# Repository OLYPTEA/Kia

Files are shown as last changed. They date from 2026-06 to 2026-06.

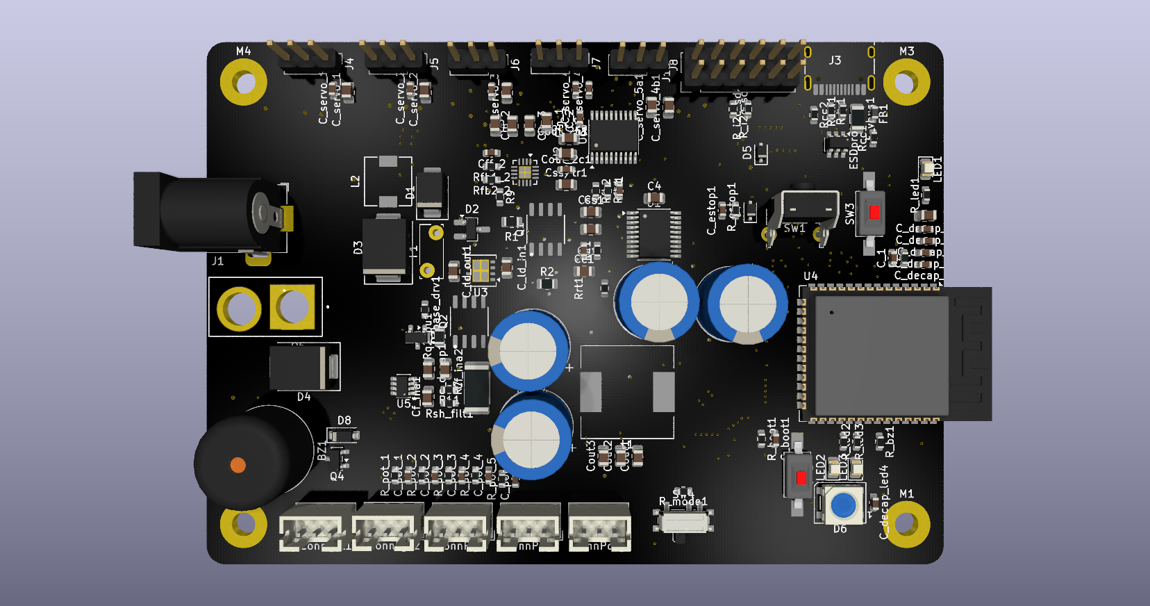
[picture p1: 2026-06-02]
1-Hardware/Kia-Arm-Ctrl.png

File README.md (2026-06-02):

#  Kia Arm Controller (ESP32-S3) By OlypTea
 (Baser sur : https://www.youtube.com/watch?v=AIsVlgopqJc )

CarteKia

Kia-Arm-Ctrl22

KiaStudio

https://github.com/user-attachments/assets/333e42ec-3789-4127-9b2e-19c26ccea488

Refonte complète (Hardware, Firmware & Software) d'un bras robotique imprimé en 3D (4 axes + pince), inspirée initialement du projet de la chaîne *Build Some Stuff*. 

Cette version abandonne le combo limité Arduino Uno + PCA9685 au profit d'une **carte sur mesure basée sur l'ESP32-S3**, capable de gérer la cinématique et l'alimentation de puissance de manière autonome.

---

##  Améliorations majeures

* **Calcul haute performance :** ESP32-S3 (Dual-core 240MHz, FPU, 16MB Flash + 8MB PSRAM Octal). Gère la cinématique directe/inverse (FK/IK) et l'interpolation par spline cubique directement en local.
* **Alimentation intégrée (6V/10A) :** Régulateur Buck synchrone TI TPS56C215 (pic à 15A) capable d'alimenter directement les servos de forte puissance (Miuzei 15 à 35kg).
* **Sécurité matérielle :** Surveillance de la puissance via INA219 et circuit d'arrêt d'urgence physique (**E-STOP** par MOSFETs) coupant la puissance sans affecter la logique du MCU.
* **Signal propre :** Abandon du PCA9685. Utilisation du périphérique natif **MCPWM** de l'ESP32-S3 avec conversion de niveau logique 3.3V vers 5V (SN74AHCT244).
* **Interface PC dédiée (Kia Studio) :** Application de contrôle et calibration 3D temps réel développée en Python (PySide6 + PyOpenGL).

---

##  Spécifications du Hardware & PCB

* **Dimensions :** 100 × 70 mm (conçu pour s'intégrer parfaitement dans l'espace de 113.5 × 80.7 mm de la base du bras / plaque MB2).
* **Stackup :** PCB 4 couches avec couches internes en cuivre épais de 2 oz (70 µm).
* **Routage :** Pistes d'alimentation VSERVO $\ge$ 3 mm et isolation stricte des masses (**Star Ground**) : connexions séparées pour le GND logique, puissance et analogique reliées en un seul point (Net tie) sous l'INA219.
* **Conception :** Réalisé sous **KiCad 10** (Schémas divisés en modules : Power, MCU, IO, Connectors).

 **Piège de routage évité :** Les GPIO 26 à 37 sont réservés à la PSRAM Octal de l'ESP32-S3 et sont strictement inutilisables.

---

##  Architecture du Firmware (Dual-Core)

Développé directement sous **ESP-IDF + FreeRTOS** pour maximiser les performances en temps réel.

* **Core 0 (PRO_CPU) : Gestion & Comms**
  * Parser USB CDC & Serveur BLE GATT (futurs services WiFi/HTTP).
  * Machine d'état principale de tout le système.
* **Core 1 (APP_CPU) : Temps Réel Strict**
  * Tâche ADC (100 Hz) : Suréchantillonnage x64, filtre EMA et hystérésis pour les 5 potentiomètres.
  * Solveur cinématique (FK/IK) et interpolation de trajectoire (Spline cubique) pour des mouvements fluides sans à-coups.
  * Driver MCPWM (50 Hz) pour le signal précis des servos (impulsions de 1 à 2 ms).
  * Supervision de sécurité (Lecture I2C en temps réel de l'INA219 & gestion de l'interruption E-STOP).

---

##  Logiciel PC : Kia Studio

Interface 3D légère basée sur une **architecture hexagonale** en Python 3.11 + PySide6 et un rendu graphique de bas niveau (pyqtgraph + PyOpenGL).

* **`proto/`** : Protocole de communication USB CDC partagé à 100 % avec le contrôleur.
* **`core/`** : Modèle cinématique pur Python et chargement des fichiers STL.
* **`ui/`** : Vue Qt, panneau de calibration 3D avec manipulation des axes XYZ (Pivot Gizmo) et sauvegarde des offsets dans un fichier de configuration JSON.

*(Note : L'application est générique. Il suffit de remplacer les modèles 3D et de rebuild l'app pour l'adapter à un autre bras possédant la même architecture).*

---

##  Modes de Fonctionnement

| Mode | Déclencheur | Logique principale | Utilisation |
| :--- | :--- | :--- | :--- |
| **Manual** | Interrupteur physique | Lecture potentiomètres $\rightarrow$ Filtre ADC $\rightarrow$ Angles $\rightarrow$ MCPWM | Test initial de chaque articulation et manipulation simple sans PC. |
| **App** | Commande PC | Cible via USB/BLE $\rightarrow$ Solveur IK $\rightarrow$ Spline cubique $\rightarrow$ MCPWM | Contrôle spatial complexe via Kia Studio, exécution de trajectoires. |
| **Calibration**| Commande / Bouton | Désactivation spline $\rightarrow$ Ajustement fin des neutres (largeur d'impulsion) $\rightarrow$ Sauvegarde NVS | Premier assemblage, remplacement de servo ou recentrage suite à un saut de dent. |
| **Fault** | E-STOP / INA219 | Coupure matérielle immédiate des servos + LED Alerte jaune & WS2812 rouge | Protection en cas de collision, blocage mécanique ou court-circuit. |

---

##  Remerciements & Références
* **Build Some Stuff** Fondateur du projet initiale
* **Espressif ESP-IDF** - Framework.
* **KiCad EDA** - Suite de conception électronique open-source.
* **PySide / Qt** - Framework UI pour Kia Studio.
* Merci aux membres de la communauté open-source pour les inspirations structurelles des bras robotiques 3D.

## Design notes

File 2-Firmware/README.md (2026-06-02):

# Kia Arm Controller — Firmware

ESP32-S3 firmware for the 4-axis + gripper robotic arm controller (PCB `Kia-Arm-Ctrl v1`).

## Stack

- **SDK**: ESP-IDF v5.3+
- **OS**: FreeRTOS (1 kHz tick, dual-core)
- **Language**: C11 + selective C++17 (no exceptions / no RTTI)
- **Build**: CMake via `idf.py`
- **Toolchain**: xtensa-esp32s3-elf-gcc 13+

## Architecture

```
app/        ModeFSM, Calibration
domain/     Kinematics (FK/IK 4DOF), JointModel
services/   Motion, Safety, CommRouter, Storage, Telemetry
hal/drv/    Servo (MCPWM), Pot (ADC continuous DMA), INA219, LED (RMT WS2812),
            Buttons (debounce), Buzzer (LEDC)
common/     err, log, ringbuf (lock-free SPSC), COBS, CRC32
```

### Real-time partitioning

| Core | Tasks |
|---|---|
| 1 (APP_CPU) | `motion` (1 kHz), `safety` (200 Hz), `pot` (ADC DMA) |
| 0 (PRO_CPU) | `usb_rx`, `mode_fsm`, `telemetry`, `btn`, `event_loop` |

Task priorities are defined in `main/app_config.h` (`KIA_PRIO_*`).
Safety has the highest priority and never blocks on I/O.

### Event bus

All cross-component coordination goes through `esp_event_loop` on `KIA_EVENT_BASE`
(see `main/app_events.h`). No globals, no implicit coupling.

## Build / Flash / Monitor

```bash
. $IDF_PATH/export.sh
idf.py set-target esp32s3
idf.py menuconfig          # adjust if needed
idf.py -p COMx flash monitor
```

To clean:
```bash
idf.py fullclean
```

## Wire protocols

### Text (debug / CLI)

Line-terminated ASCII. Commands :

```
PING                                  → PONG fw=1.0.0
STATUS                                → STATUS J=[...] XYZP=[...] I=... FAULT=... SRC=...
J <id> <deg> [duration]               → OK | ERR ...
XYZ <x> <y> <z> <pitch> [duration]    → OK | ERR ...
MODE MANUAL|APP|HOLD                  → OK
HOME                                  → OK
HOLD                                  → OK
ARM                                   → OK | ERR
CLEAR                                 → OK | ERR
SAVE                                  → OK
HELP
```

### Binary (app, COBS + CRC32)

Frames terminated by `0x00`. Body (after COBS decode):

```
struct frame {
  u8   op;
  u8   flags;
  u16  seq;
  u32  crc32;       /* CRC of op|flags|seq|payload */
  u8   payload[];
}
```

Opcodes TBD — currently the dispatcher is a stub. Extension point in
`components/svc_comm/proto_binary.c`.

## Safety model

1. **HW E-STOP** : `GPIO40` drives the P-MOSFET that gates `+VSERVO`.
   Independent of firmware liveness.
2. **HW E-STOP IRQ** : `GPIO18` falling edge → kill rail + raise `FAULT`.
3. **INA219 supervisor** : 200 Hz. Trips on instantaneous I > 8 A or
   sustained average > 5 A.
4. **Brownout detector** : hardware level 7.
5. **Task WDT** : 3 s, registered on safety task.
6. **Soft joint limits** : enforced in `dom_joint_clamp` and in motion controller.

To clear a soft fault: `CLEAR`. To clear E-STOP: release the physical button.

## Calibration

Stored in NVS namespace `kia_cal`. Per-servo: offset, pulse min/max,
inversion, angle window. Per-pot: raw min/max.

Capture from CLI :
```
J 0 0          # drive joint 0 to where you want zero
# then via dedicated calibration cmd (TODO: CAL J0 ZERO)
SAVE           # persist to NVS
```

## File layout

```
firmware/
├── CMakeLists.txt
├── sdkconfig.defaults
├── partitions.csv
├── main/
│   ├── main.c
│   ├── app_config.h         ← single source of truth for pins, limits, rates
│   └── app_events.h
├── components/
│   ├── common/              ← err, log, ringbuf, COBS, CRC32
│   ├── drv_servo/           ← MCPWM, 5 channels
│   ├── drv_pot/             ← ADC continuous + EMA + adaptive hysteresis
│   ├── drv_ina219/          ← I²C current monitor
│   ├── drv_led/             ← WS2812 (RMT) + status/fault GPIOs
│   ├── drv_buttons/         ← E-STOP + mode (ISR + debounce)
│   ├── drv_buzzer/          ← LEDC PWM tones
│   ├── dom_joint/           ← per-joint spec + state + limit clamp
│   ├── dom_kinematics/      ← FK + IK 4DOF closed-form
│   ├── svc_safety/          ← supervisor + fault FSM
│   ├── svc_motion/          ← 1 kHz controller + quintic trajectory
│   ├── svc_comm/            ← router + USB CDC + text + binary protocols
│   ├── svc_storage/         ← NVS wrappers, calibration persistence
│   ├── svc_telemetry/       ← periodic broadcast on all transports
│   ├── app_mode_fsm/        ← Boot → Idle → Manual/App/Calib/Fault/E-STOP
│   └── app_calibration/     ← capture routines
└── tests/                   ← unit tests (Unity, TODO)
```

## Coding conventions

- snake_case, header guards via `#pragma once`
- static for everything not in the public header
- no globals; module state held in a single static struct
- error type : `esp_err_t` augmented by `kia_err_t` codes
- macros : `KIA_CHK(expr)` aborts on error (init time), `KIA_RET(expr)` returns
- clang-format provided

## Status (firmware roadmap)

- [x] BLE NimBLE GATT transport (custom service, RX write + TX notify)
- [x] Binary opcode dispatch (system / motion / mode / storage / cal / OTA)
- [x] CAL CLI subcommands (`CAL J<i> ZERO|MIN|MAX`, `CAL P<i> MIN|MAX`, `CAL GEOM`)
- [x] OTA over USB CDC / BLE (`svc_ota` + opcodes 0x50–0x53)
- [x] Trajectory queue (`move_queue`, FreeRTOS-safe ring)
- [x] Jerk-limited S-curve profile (`traj_scurve_*`, switchable at runtime)
- [x] Cartesian straight-line path (`cart_path_plan_line`, subdivision + per-segment IK)
- [x] Unit tests Unity (kinematics, COBS, CRC32, ringbuf, trajectory) — `tests/`
- [x] Host CLI Python (`tools/kia_cli.py` — serial + BLE, text + binary + OTA push)
- [ ] PID closed-loop (waiting for joint encoders hardware)
- [ ] BLE pairing / bonding for production
- [ ] Web-based telemetry dashboard

## Wire protocol — binary opcodes

| Op | Direction | Body (LE) |
|---|---|---|
| 0x01 PING | req | — |
| 0x81 PONG | rsp | u8 maj, u8 min, u8 patch |
| 0x02 GET_STATUS  | req | — |
| 0x82 STATUS | rsp | 4×f32 joints, f32 grip, 3×f32 xyz, f32 pitch, u32 cur_ma, u8 fault, u8 src, u8 idle, u8 _ |
| 0x10 SET_JOINT | req | u8 idx, f32 deg, f32 dur |
| 0x11 SET_JOINTS  | req | 4×f32 joints, f32 grip, f32 dur |
| 0x12 SET_XYZ | req | 4×f32 pose, f32 dur |
| 0x13 HOME / 0x14 HOLD | req | — |
| 0x20 MODE_SET | req | u8 mode |
| 0x21 ARM / 0x22 CLEAR | req | — |
| 0x30 SAVE / 0x31 LOAD / 0x3F FACTORY | req | — |
| 0x50 OTA_BEGIN | req | u32 total, u16 chunk, u32 crc32 |
| 0x51 OTA_CHUNK | req | u32 offset, bytes data |
| 0x52 OTA_END / 0x53 OTA_ABORT | req | — |
| 0xF0 TELEMETRY | async | same payload as STATUS |
| 0xFE ACK / 0xFF NACK | rsp | (NACK) u8 reason |

NACK reasons: 1=BAD_OP 2=BAD_LEN 3=BAD_ARG 4=LIMIT 5=UNREACHABLE 6=FAULT 7=BUSY 8=NOMEM 9=BAD_STATE 0xFE=NOT_IMPL 0xFF=INTERNAL

## BLE service

| Item | Value |
|---|---|
| Service UUID  | custom 128-bit (see `transport_ble.c`) |
| RX charac | write / write-no-rsp — host → device frames |
| TX charac | notify — device → host frames |
| Device name | `KiaArm` |

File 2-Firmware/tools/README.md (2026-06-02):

# Kia Arm — Host tools

## kia_cli.py

Interactive CLI for the Kia Arm controller, supports both **USB CDC** (text + binary)
and **BLE** transports.

### Install

```bash
pip install -r requirements.txt
```

### Usage

```bash
# USB serial
python kia_cli.py serial COM5
python kia_cli.py serial /dev/ttyACM0 -b 115200

# BLE (auto-scan for "KiaArm")
python kia_cli.py ble
python kia_cli.py ble --name MyKia
```

### Commands

Text protocol (line-based, parsed by `proto_text` on device):

```
PING
STATUS
J 0 30 1.5
XYZ 150 0 120 -30 2.0
MODE MANUAL|APP|HOLD
HOME / HOLD / ARM / CLEAR / SAVE
CAL J<i> ZERO|MIN|MAX
CAL P<i> MIN|MAX
CAL GEOM <base_h> <upper> <fore> <tool>
CAL LOAD | FACTORY
HELP
```

Binary helpers (encoded COBS+CRC32 frames):

```
bping
bjoint <i> <deg>
bxyz <x y z pitch>
bhome / bsave / barm / bclear
ota <firmware.bin>          # push OTA
tlm                         # print last decoded telemetry
```

Type `q` or `exit` to quit.

### Architecture

```
KiaClient
   ├─ Transport (Serial | BLE)  — bytes in/out
   ├─ Text frames   — newline terminated
   └─ Binary frames — COBS(0x00 delim) + [op|flags|seq|crc32|body]
```

Telemetry frames (opcode 0xF0) are decoded into a `Status` dataclass and
exposed via `client.last_telemetry`.

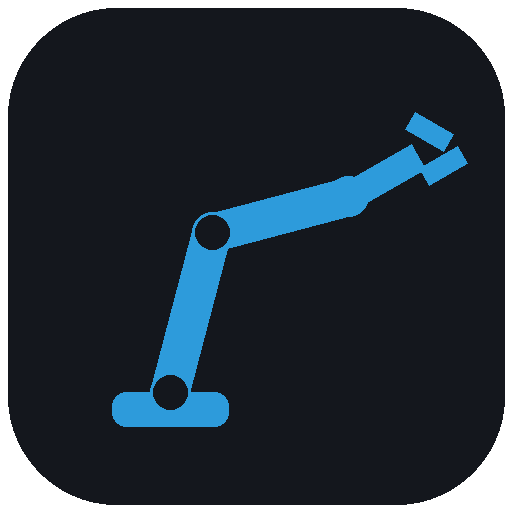
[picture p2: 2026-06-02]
3-Software/packaging/kia_preview.png

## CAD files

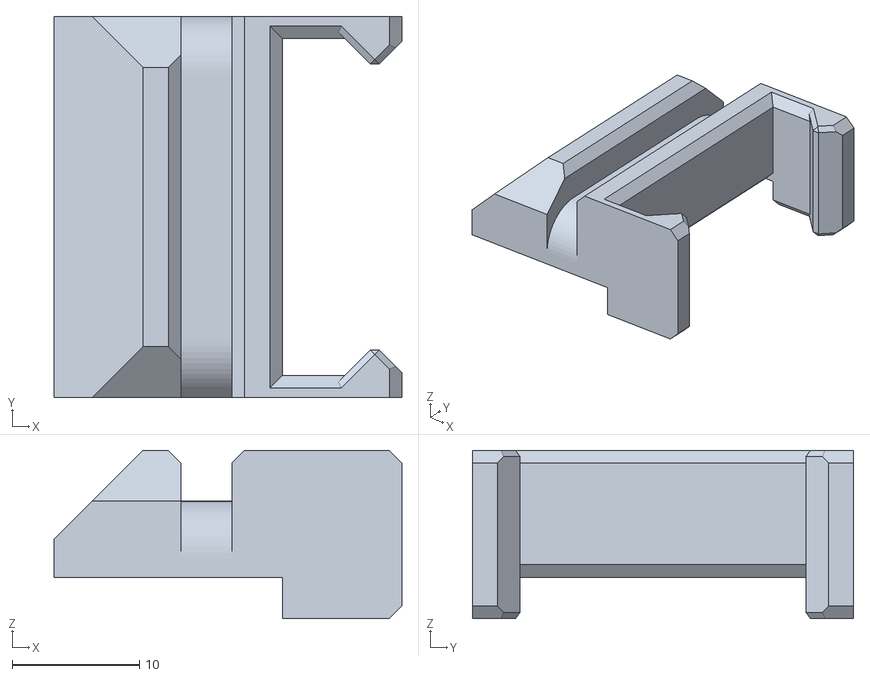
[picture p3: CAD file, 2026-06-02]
3-Software/kia_studio/resources/meshes/Grip2.stl
27.4 x 30.0 x 13.2

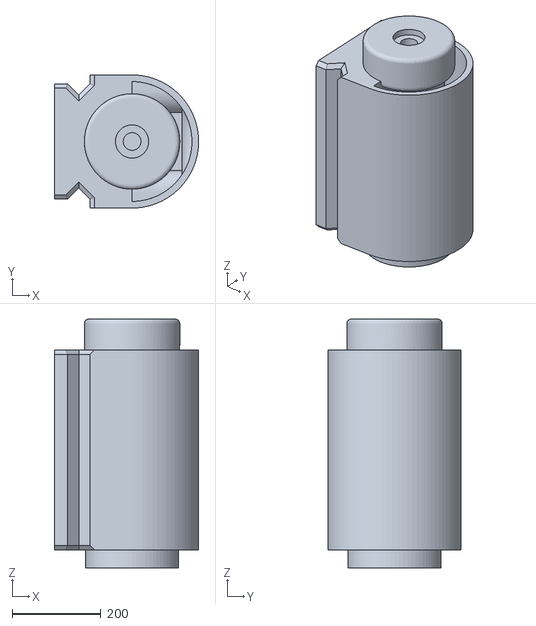
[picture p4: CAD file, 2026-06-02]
3-Software/kia_studio/resources/meshes/Poignet.stl
324.9 x 300.0 x 561.0

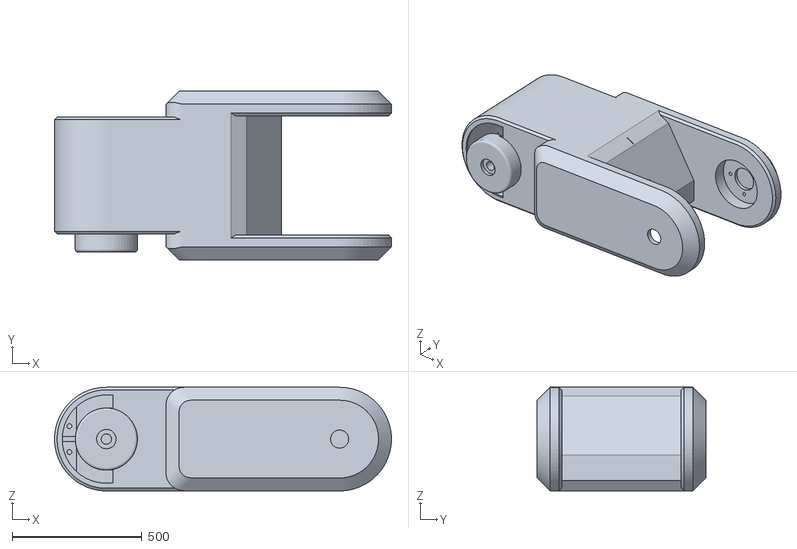
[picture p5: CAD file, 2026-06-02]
3-Software/kia_studio/resources/meshes/Epaule.stl
1300.0 x 650.5 x 399.3

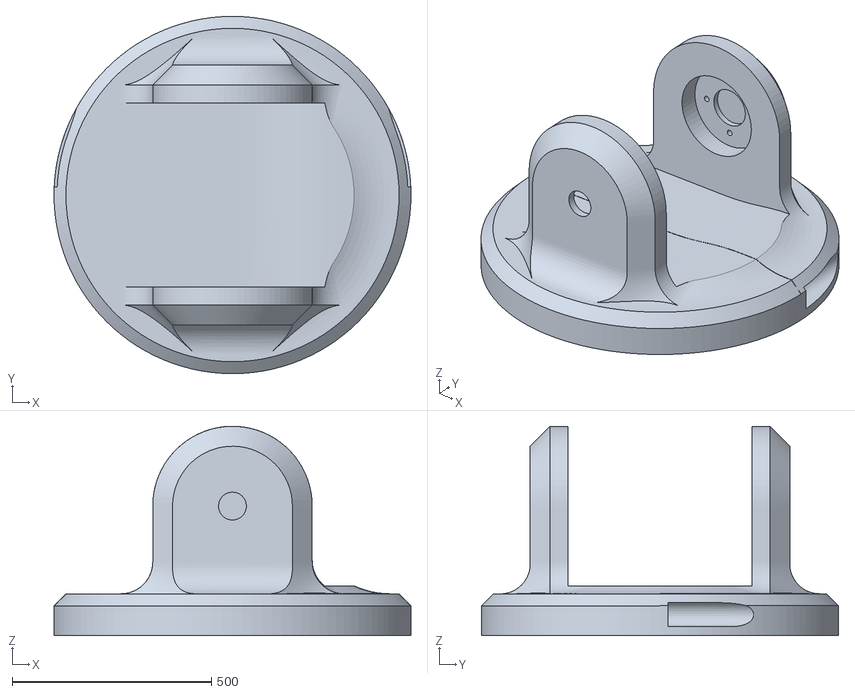
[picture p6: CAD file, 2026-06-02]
3-Software/kia_studio/resources/meshes/Base1.stl
895.0 x 895.7 x 525.2

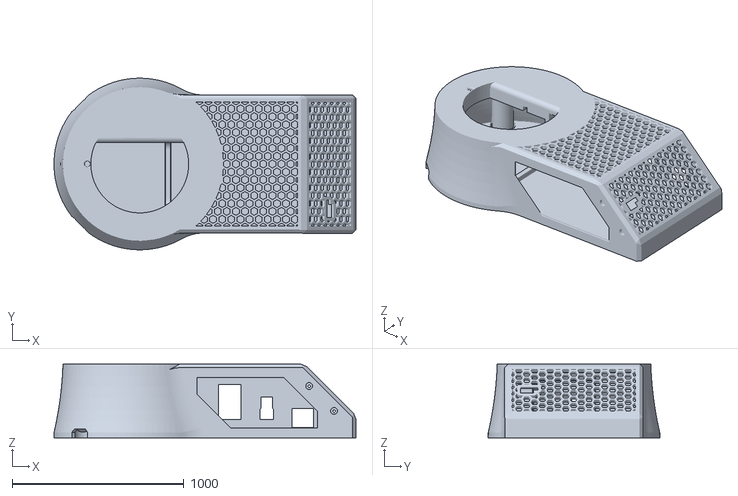
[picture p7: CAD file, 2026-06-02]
3-Software/kia_studio/resources/meshes/Bati.stl
1759.7 x 1000.0 x 430.3

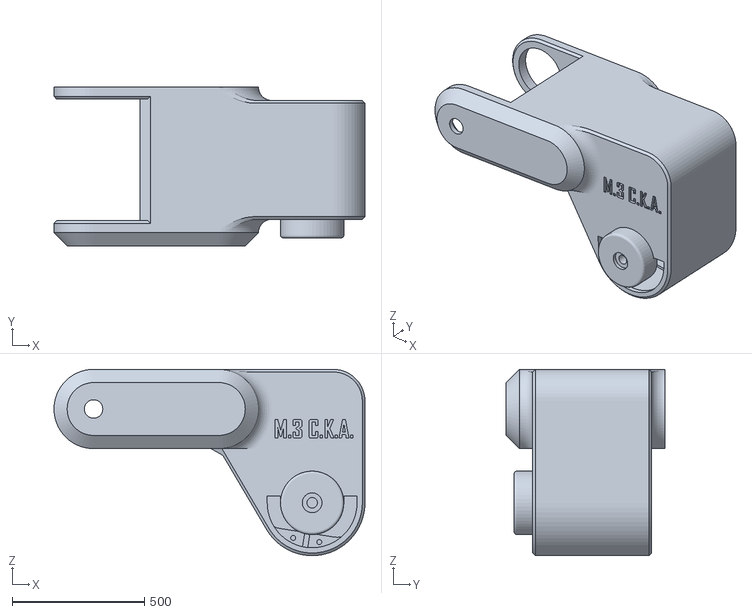
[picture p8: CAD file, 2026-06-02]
3-Software/kia_studio/resources/meshes/Coude.stl
1176.8 x 600.0 x 705.0

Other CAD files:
3-Software/kia_studio/resources/meshes/Grip1.stl

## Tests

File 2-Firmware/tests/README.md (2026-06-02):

# Kia Arm — Unit tests

ESP-IDF Unity test app. Runs on ESP32-S3 hardware or QEMU.

## Build & run

```bash
cd firmware/tests
idf.py set-target esp32s3
idf.py build flash monitor
```

Filter by tag (e.g. only kinematics):

```
[kin]
[cobs]
[crc32]
[ringbuf]
[traj]
```

Type the filter (with brackets) in the monitor prompt after Unity menu.

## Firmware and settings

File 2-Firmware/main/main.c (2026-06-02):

#include <stdio.h>

#include "esp_event.h"
#include "esp_log.h"
#include "esp_system.h"
#include "esp_task_wdt.h"
#include "freertos/FreeRTOS.h"
#include "freertos/task.h"
#include "nvs_flash.h"

#include "app_config.h"
#include "app_events.h"

#include "app_mode_fsm.h"
#include "drv_buttons.h"
#include "drv_buzzer.h"
#include "drv_ina219.h"
#include "drv_led.h"
#include "drv_pot.h"
#include "drv_servo.h"
#include "kia_err.h"
#include "svc_comm.h"
#include "svc_motion.h"
#include "svc_ota.h"
#include "svc_safety.h"
#include "svc_storage.h"
#include "svc_telemetry.h"

ESP_EVENT_DEFINE_BASE(KIA_EVENT_BASE);

static const char *TAG = "main";

static void on_kia_event(void *arg, esp_event_base_t base, int32_t id, void *data)
{
    (void)arg;
    (void)base;
    (void)data;
    switch (id) {
        case KIA_EVT_ESTOP_TRIGGERED: ESP_LOGW(TAG, "ESTOP TRIGGERED"); break;
        case KIA_EVT_ESTOP_CLEARED: ESP_LOGI(TAG, "ESTOP cleared"); break;
        case KIA_EVT_FAULT_RAISED: ESP_LOGE(TAG, "FAULT raised"); break;
        case KIA_EVT_FAULT_CLEARED: ESP_LOGI(TAG, "Fault cleared"); break;
        case KIA_EVT_MODE_CHANGED: ESP_LOGI(TAG, "Mode changed"); break;
        case KIA_EVT_OVERCURRENT: SP_LOGW(TAG, "OVERCURRENT"); break;
        default: break;
    }
}

static void boot_banner(void)
{
    ESP_LOGI(TAG, "Kia Arm Controller fw v%d.%d.%d", KIA_FW_VERSION_MAJOR, KIA_FW_VERSION_MINOR,
             KIA_FW_VERSION_PATCH);
    ESP_LOGI(TAG, "Build: %s %s", __DATE__, __TIME__);
}

void app_main(void)
{
    boot_banner();

    esp_err_t err = nvs_flash_init();
    if (err == ESP_ERR_NVS_NO_FREE_PAGES || err == ESP_ERR_NVS_NEW_VERSION_FOUND) {
        ESP_ERROR_CHECK(nvs_flash_erase());
        ESP_ERROR_CHECK(nvs_flash_init());
    } else {
        ESP_ERROR_CHECK(err);
    }

    ESP_ERROR_CHECK(esp_event_loop_create_default());
    ESP_ERROR_CHECK(esp_event_handler_register(KIA_EVENT_BASE, ESP_EVENT_ANY_ID, on_kia_event, NULL));

    KIA_CHK(svc_storage_init());
    KIA_CHK(drv_led_init());
    drv_led_set_mode_color(DRV_LED_COLOR_BOOT);

    KIA_CHK(drv_buzzer_init());
    KIA_CHK(drv_buttons_init());
    KIA_CHK(drv_servo_init());
    KIA_CHK(drv_pot_init());
    KIA_CHK(drv_ina219_init());

    KIA_CHK(svc_safety_init());      /* must come before motion */
    KIA_CHK(svc_motion_init());
    KIA_CHK(app_mode_fsm_init());
    KIA_CHK(svc_ota_init());
    KIA_CHK(svc_telemetry_init());
    KIA_CHK(svc_comm_init());

    drv_buzzer_beep_ok();
    drv_led_set_mode_color(DRV_LED_COLOR_READY);

    ESP_ERROR_CHECK(esp_event_post(KIA_EVENT_BASE, KIA_EVT_BOOT_DONE, NULL, 0, portMAX_DELAY));
    ESP_LOGI(TAG, "Boot complete");

    /* app_main can return on IDF v5+; idle is handled by tasks. */
}

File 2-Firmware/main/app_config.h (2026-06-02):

#pragma once

#include <stdint.h>

#define KIA_FW_VERSION_MAJOR 1
#define KIA_FW_VERSION_MINOR 0
#define KIA_FW_VERSION_PATCH 0

/* === GPIO map (locked, see docs/02-pinout.md) ============================ */
#define KIA_GPIO_POT_BASE     1
#define KIA_GPIO_POT_SHOULDER 2
#define KIA_GPIO_POT_ELBOW    4
#define KIA_GPIO_POT_WRIST    5
#define KIA_GPIO_POT_GRIP     6

#define KIA_GPIO_PWM_BASE     7
#define KIA_GPIO_PWM_SHOULDER 8
#define KIA_GPIO_PWM_ELBOW    9
#define KIA_GPIO_PWM_WRIST    10
#define KIA_GPIO_PWM_GRIP     11

#define KIA_GPIO_I2C_SDA 12
#define KIA_GPIO_I2C_SCL 13

#define KIA_GPIO_SPI_SCLK 14
#define KIA_GPIO_SPI_MOSI 15
#define KIA_GPIO_SPI_MISO 16
#define KIA_GPIO_SPI_CS0  17

#define KIA_GPIO_ESTOP     18
#define KIA_GPIO_MODE_SEL  21
#define KIA_GPIO_BOOT      0

#define KIA_GPIO_LED_STATUS 38
#define KIA_GPIO_LED_FAULT  39
#define KIA_GPIO_SERVO_EN   40
#define KIA_GPIO_BUZZER     41
#define KIA_GPIO_WS2812     48

/* === I2C ================================================================= */
#define KIA_I2C_PORT     0
#define KIA_I2C_FREQ_HZ  400000
#define KIA_I2C_INA219_ADDR 0x40

/* === Joints ============================================================== */
#define KIA_JOINT_COUNT 5
enum {
    KIA_J_BASE = 0,
    KIA_J_SHOULDER,
    KIA_J_ELBOW,
    KIA_J_WRIST,
    KIA_J_GRIP,
};

/* === Servo electrical config ============================================= */
#define KIA_SERVO_PWM_FREQ_HZ      50
#define KIA_SERVO_PULSE_MIN_US     500
#define KIA_SERVO_PULSE_MAX_US     2500
#define KIA_SERVO_PULSE_NEUTRAL_US 1500
#define KIA_SERVO_RESOLUTION_HZ    1000000  /* 1 MHz -> 1 us per tick */

/* === Joint geometry (DH-like, in mm) — TO MEASURE/CALIBRATE ============== */
#define KIA_LINK_BASE_HEIGHT_MM  60.0f
#define KIA_LINK_UPPER_ARM_MM    105.0f
#define KIA_LINK_FOREARM_MM      100.0f
#define KIA_LINK_TOOL_MM         85.0f

/* === Joint software limits (deg) ========================================= */
#define KIA_LIM_BASE_MIN_DEG     -90.0f
#define KIA_LIM_BASE_MAX_DEG     90.0f
#define KIA_LIM_SHOULDER_MIN_DEG -10.0f
#define KIA_LIM_SHOULDER_MAX_DEG 170.0f
#define KIA_LIM_ELBOW_MIN_DEG    -135.0f
#define KIA_LIM_ELBOW_MAX_DEG    135.0f
#define KIA_LIM_WRIST_MIN_DEG    -90.0f
#define KIA_LIM_WRIST_MAX_DEG    90.0f
#define KIA_LIM_GRIP_MIN_DEG     0.0f
#define KIA_LIM_GRIP_MAX_DEG     90.0f

/* === Slew rate (deg/s) =================================================== */
#define KIA_SLEW_MAX_DEGPS 240.0f

/* === ADC pots ============================================================ */
#define KIA_ADC_UNIT             0  /* ADC1 */
#define KIA_ADC_ATTEN            ADC_ATTEN_DB_12
#define KIA_ADC_BITWIDTH         12
#define KIA_ADC_SAMPLE_RATE_HZ   32000
#define KIA_ADC_OVERSAMPLE       64
#define KIA_ADC_EMA_ALPHA_Q16    13107  /* 0.20 in Q16 */
#define KIA_ADC_HYST_BASE_LSB    8
#define KIA_ADC_HYST_GAIN_Q16    16384  /* 0.25 in Q16 */

/* === Safety ============================================================== */
#define KIA_SAFETY_RATE_HZ       200
#define KIA_SAFETY_I_LIMIT_MA    8000     /* over-current threshold */
#define KIA_SAFETY_I_AVG_LIMIT_MA 5000    /* sustained current */
#define KIA_SAFETY_I_AVG_WINDOW_MS 1500
#define KIA_SAFETY_V_BUS_MIN_MV  4500     /* INA219 bus V should be ~6 V */

/* === Motion control ====================================================== */
#define KIA_CTRL_RATE_HZ         1000
#define KIA_TRAJECTORY_QUEUE_LEN 32

/* === Comms =============================================================== */
#define KIA_COMM_RX_BUF          1024
#define KIA_COMM_TX_BUF          1024
#define KIA_COMM_FRAME_MAX       512

/* === Task priorities (FreeRTOS, 0=lowest) ================================ */
#define KIA_PRIO_IDLE      0
#define KIA_PRIO_TELEMETRY 3
#define KIA_PRIO_COMM      6
#define KIA_PRIO_MODE_FSM  7
#define KIA_PRIO_MOTION    18  /* hard real-time */
#define KIA_PRIO_SAFETY    22  /* highest */

/* === Task stacks (bytes) ================================================= */
#define KIA_STACK_MOTION    8192
#define KIA_STACK_SAFETY    4096
#define KIA_STACK_COMM      6144
#define KIA_STACK_FSM       4096
#define KIA_STACK_TELEMETRY 4096

/* === Cores =============================================================== */
#define KIA_CORE_RT  1  /* APP_CPU */
#define KIA_CORE_IO  0  /* PRO_CPU */

/* === NVS namespaces ====================================================== */
#define KIA_NVS_NS_CAL      "kia_cal"
#define KIA_NVS_NS_CFG      "kia_cfg"

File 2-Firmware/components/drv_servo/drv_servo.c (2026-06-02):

#include "drv_servo.h"

#include <math.h>
#include <string.h>

#include "driver/gpio.h"
#include "driver/mcpwm_prelude.h"
#include "esp_log.h"
#include "freertos/FreeRTOS.h"
#include "freertos/semphr.h"

#include "app_config.h"
#include "kia_err.h"

static const char *TAG = "drv_servo";

typedef struct {
    mcpwm_cmpr_handle_t cmpr;
    mcpwm_gen_handle_t  gen;
    drv_servo_cal_t     cal;
    float               cur_deg;
} servo_chan_t;

static struct {
    mcpwm_timer_handle_t timer;
    mcpwm_oper_handle_t  oper[3];
    servo_chan_t         chan[DRV_SERVO_COUNT];
    SemaphoreHandle_t    mtx;
    bool                 enabled;
    bool                 ready;
} S;

static const int s_gpio[DRV_SERVO_COUNT] = {
    KIA_GPIO_PWM_BASE, KIA_GPIO_PWM_SHOULDER, KIA_GPIO_PWM_ELBOW, KIA_GPIO_PWM_WRIST, KIA_GPIO_PWM_GRIP,
};

static const drv_servo_cal_t s_default_cal[DRV_SERVO_COUNT] = {
    [KIA_J_BASE]     = {500, 2500, -90, 90, 0, false},
    [KIA_J_SHOULDER] = {500, 2500, 0, 180, -90, false},
    [KIA_J_ELBOW]    = {500, 2500, -135, 135, 0, false},
    [KIA_J_WRIST]    = {500, 2500, -90, 90, 0, false},
    [KIA_J_GRIP]     = {500, 2500, 0, 90, 0, false},
};

static uint32_t deg_to_pulse(uint8_t idx, float deg)
{
    const drv_servo_cal_t *c = &S.chan[idx].cal;
    float                  a = c->inverted ? -deg : deg;
    a += c->offset_deg;
    a            = kia_clampf(a, c->angle_min_deg, c->angle_max_deg);
    float t      = (a - c->angle_min_deg) / (c->angle_max_deg - c->angle_min_deg);
    float pulse  = (float)c->pulse_min_us + t * (float)(c->pulse_max_us - c->pulse_min_us);
    return (uint32_t)pulse;
}

esp_err_t drv_servo_init(void)
{
    if (S.ready) return ESP_OK;
    memset(&S, 0, sizeof(S));

    gpio_config_t en = {
        .pin_bit_mask = 1ULL << KIA_GPIO_SERVO_EN,
        .mode         = GPIO_MODE_OUTPUT,
        .pull_up_en   = 0,
        .pull_down_en = 1,
        .intr_type    = GPIO_INTR_DISABLE,
    };
    KIA_RET(gpio_config(&en));
    gpio_set_level(KIA_GPIO_SERVO_EN, 0);

    S.mtx = xSemaphoreCreateMutex();
    KIA_RET_IF(!S.mtx, ESP_ERR_NO_MEM);

    mcpwm_timer_config_t tcfg = {
        .group_id     = 0,
        .clk_source   = MCPWM_TIMER_CLK_SRC_DEFAULT,
        .resolution_hz = KIA_SERVO_RESOLUTION_HZ,
        .period_ticks  = KIA_SERVO_RESOLUTION_HZ / KIA_SERVO_PWM_FREQ_HZ,
        .count_mode    = MCPWM_TIMER_COUNT_MODE_UP,
    };
    KIA_RET(mcpwm_new_timer(&tcfg, &S.timer));

    for (int i = 0; i < 3; ++i) {
        mcpwm_operator_config_t ocfg = {.group_id = 0};
        KIA_RET(mcpwm_new_operator(&ocfg, &S.oper[i]));
        KIA_RET(mcpwm_operator_connect_timer(S.oper[i], S.timer));
    }

    for (int i = 0; i < DRV_SERVO_COUNT; ++i) {
        S.chan[i].cal     = s_default_cal[i];
        S.chan[i].cur_deg = 0;

        mcpwm_comparator_config_t ccfg = {.flags.update_cmp_on_tez = true};
        KIA_RET(mcpwm_new_comparator(S.oper[i / 2], &ccfg, &S.chan[i].cmpr));

        mcpwm_generator_config_t gcfg = {.gen_gpio_num = s_gpio[i]};
        KIA_RET(mcpwm_new_generator(S.oper[i / 2], &gcfg, &S.chan[i].gen));

        KIA_RET(mcpwm_comparator_set_compare_value(S.chan[i].cmpr, KIA_SERVO_PULSE_NEUTRAL_US));

        KIA_RET(mcpwm_generator_set_action_on_timer_event(
            S.chan[i].gen, MCPWM_GEN_TIMER_EVENT_ACTION(
                               MCPWM_TIMER_DIRECTION_UP, MCPWM_TIMER_EVENT_EMPTY, MCPWM_GEN_ACTION_HIGH)));
        KIA_RET(mcpwm_generator_set_action_on_compare_event(
            S.chan[i].gen, MCPWM_GEN_COMPARE_EVENT_ACTION(
                               MCPWM_TIMER_DIRECTION_UP, S.chan[i].cmpr, MCPWM_GEN_ACTION_LOW)));
    }

    KIA_RET(mcpwm_timer_enable(S.timer));
    KIA_RET(mcpwm_timer_start_stop(S.timer, MCPWM_TIMER_START_NO_STOP));

    S.ready = true;
    ESP_LOGI(TAG, "MCPWM %d channels initialised", DRV_SERVO_COUNT);
    return ESP_OK;
}

esp_err_t drv_servo_enable(bool on)
{
    KIA_RET_IF(!S.ready, ESP_ERR_INVALID_STATE);
    gpio_set_level(KIA_GPIO_SERVO_EN, on ? 1 : 0);
    S.enabled = on;
    return ESP_OK;
}

bool drv_servo_is_enabled(void) { return S.enabled; }

esp_err_t drv_servo_set_calibration(uint8_t idx, const drv_servo_cal_t *cal)
{
    KIA_RET_IF(idx >= DRV_SERVO_COUNT || !cal, ESP_ERR_INVALID_ARG);
    xSemaphoreTake(S.mtx, portMAX_DELAY);
    S.chan[idx].cal = *cal;
    xSemaphoreGive(S.mtx);
    return ESP_OK;
}

esp_err_t drv_servo_get_calibration(uint8_t idx, drv_servo_cal_t *out)
{
    KIA_RET_IF(idx >= DRV_SERVO_COUNT || !out, ESP_ERR_INVALID_ARG);
    xSemaphoreTake(S.mtx, portMAX_DELAY);
    *out = S.chan[idx].cal;
    xSemaphoreGive(S.mtx);
    return ESP_OK;
}

esp_err_t drv_servo_set_angle(uint8_t idx, float deg)
{
    KIA_RET_IF(idx >= DRV_SERVO_COUNT, ESP_ERR_INVALID_ARG);
    KIA_RET_IF(!S.ready, ESP_ERR_INVALID_STATE);
    uint32_t us = deg_to_pulse(idx, deg);
    esp_err_t e = mcpwm_comparator_set_compare_value(S.chan[idx].cmpr, us);
    if (e == ESP_OK) S.chan[idx].cur_deg = deg;
    return e;
}

float drv_servo_get_angle(uint8_t idx)
{
    if (idx >= DRV_SERVO_COUNT) return 0;
    return S.chan[idx].cur_deg;
}

esp_err_t drv_servo_set_pulse_us(uint8_t idx, uint32_t us)
{
    KIA_RET_IF(idx >= DRV_SERVO_COUNT, ESP_ERR_INVALID_ARG);
    KIA_RET_IF(us < KIA_SERVO_PULSE_MIN_US || us > KIA_SERVO_PULSE_MAX_US, ESP_ERR_INVALID_ARG);
    return mcpwm_comparator_set_compare_value(S.chan[idx].cmpr, us);
}

esp_err_t drv_servo_home_all(void)
{
    for (uint8_t i = 0; i < DRV_SERVO_COUNT; ++i) {
        const drv_servo_cal_t *c   = &S.chan[i].cal;
        float                  mid = 0.5f * (c->angle_min_deg + c->angle_max_deg) - c->offset_deg;
        KIA_RET(drv_servo_set_angle(i, mid));
    }
    return ESP_OK;
}
